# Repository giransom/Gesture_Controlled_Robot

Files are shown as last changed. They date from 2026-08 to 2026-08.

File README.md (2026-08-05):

# Gesture_Controlled_Robot
The goal of the project is for a robot car to mover based on the movement of the hand controller. This project utilizes UART communication through HC 05 bluetooth modules to create send and receive messages between an UNO &amp; Nano.

Headstone Image

# Code
Base Project Code
- [Complete Hand Module Code: Nano](Gesture_Controlled_Robot_Hand_Code.ino)
- [Complete Robot Car Module Code](Gesture_Controlled_Robot_Robot_Code.ino)
- [Bluetooth Connection Test: UNO](Bluetooth_Tester_UNO.ino)
- [Bluetooth Connection Test: BLE 33 Sense](Bluetooth_Tester_BLE_33_Sense.ino)
- [AT Mode Code: UNO](AT_Mode_UNO.ino)
- [AT Mode Code: BLE 33 Sense](AT_Mode_BLE_33_Sense.ino)

HPV Camera & Screen
- [Stream Live Video from Camera](server.py)
- [Stream Capture Images from Camera](image_stream_server.py)
- [Setting Up IP Adrdess](setup_server.py)
- [Final Camera Live Stream Code](ESP32_Camera.ino)
- [Final Display Live Stream Code](Display_Camera.ino)

# Schematics
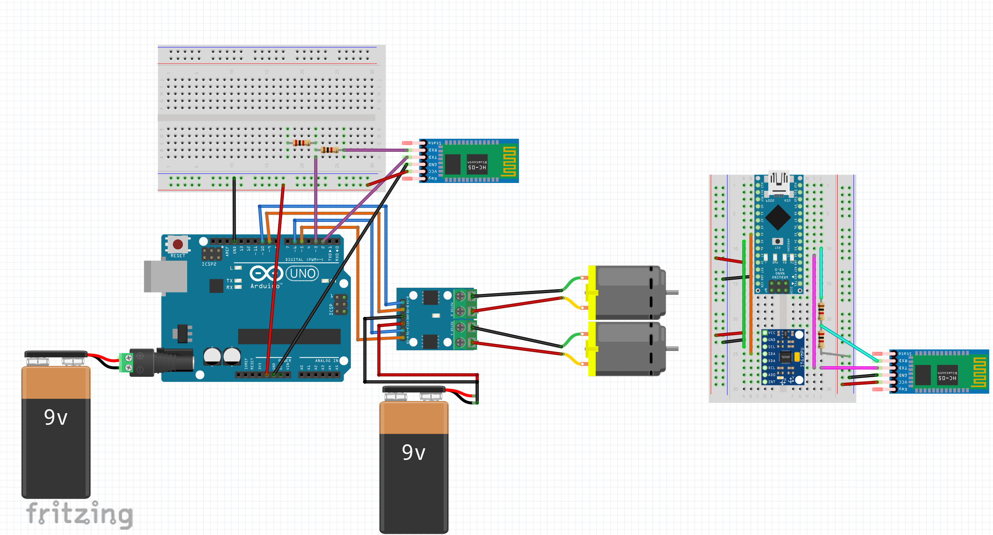
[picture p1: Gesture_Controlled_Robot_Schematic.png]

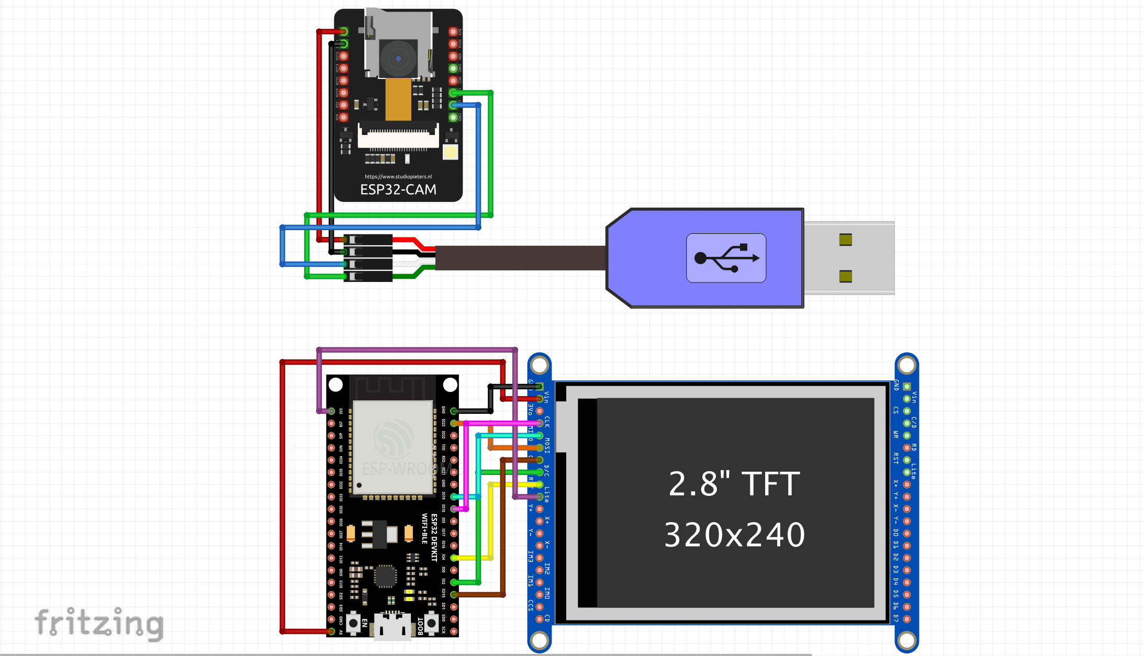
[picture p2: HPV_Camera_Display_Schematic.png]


# Project Notes: Challenges & Fixes
  In the completion of this project there were many challenges to overcome. The first challenge faced was in connecting the bluetooth modules together. I based my original wiring based on the original project I found my HC 05 modules would not enter AT mode and respond to commands. When I further researched the modules independently I found the EN pin needed to be fed 3.3 V when entering AT mode. My next challenge faced was ensuring the actual modules not only were connected by checking the blinking rate, but sending actual characters between each other. My solution found was making sure the correct baud rate was set (38400 baud) in AT mode and then setting the Arduino's Serial bauds to be different values (Uno @ 115200 and Nano BLE 33 @ 9600). My next challenge faced was providing enough voltage to the motor driver to run while disconnected from the computer. The solution to this issue was to wire a separate 9V battery to the motor driver so it had a consistent source of voltage. 
  After finishing the base model of the project I decided to add an additional HPV camera with touch screen display. In adding my addition components I ran into many issues, starting with issues of my camera connecting to the wifi. Originally when I setup my camera the streaming worked, but after restarting the camera it suddenly did not connect to wifi anymore. Eventually I found that I forgot to add an additional antenna the camera came with which prevented the board from reaching the wifi. After that initial issue it was simple to start to set up the display screen and ensure it could pick up the streamed IP website. When my display screen finally started to stream the video feed there was issues with setting ip the actual pixel setting since the JPEG decoder was not adjusted correctly.

# Bill of Materials
Base Project Parts
| **Part** | **Note** | **Price** | **Link** |
|:--:|:--:|:--:|:--:|
| Sunfounder Kit | Has main components including Arduino Uno, ultrasonic sensor, etc. | $62.99 | <a href="https://www.amazon.com/SunFounder-Compatible-Tutorials-Including-Controller/dp/B0B778L1DZ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"> Link </a> |
| Arduino Nano BLE 33 Sense | Has main components including Arduino Uno, ultrasonic sensor, etc. | $39.7 | <a href="https://www.amazon.com/Arduino-Nano-Sense-headers-ABX00070/dp/B0BQHZ88WD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"> Link </a> |
| Accelerometer | Has main components including Arduino Uno, ultrasonic sensor, etc. | $9 | <a href="https://www.amazon.com/dp/B0D2TJVMNY?ref=fed_asin_title"> Link </a> |
| HC 05 Bluetooth Modules | Has main components including Arduino Uno, ultrasonic sensor, etc. | $9 | <a href="https://www.amazon.com/DSD-TECH-HC-05-Pass-through-Communication/dp/B01G9KSAF6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"> Link </a> |
| Breadboard Kit | Has main components including Arduino Uno, ultrasonic sensor, etc. | $8.69 | <a href="https://www.amazon.com/Breadboards-Solderless-Breadboard-Distribution-Connecting/dp/B07DL13RZH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"> Link </a> |
| 9V Batteries | Has main components including Arduino Uno, ultrasonic sensor, etc. | $8.69 | <a href="https://www.amazon.com/Amazon-Basics-Performance-All-Purpose-Batteries/dp/B00MH4QM1S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"> Link </a> |
| Velcro Tape | Has main components including Arduino Uno, ultrasonic sensor, etc. | $8 | <a href="https://www.amazon.com/Art3d-Sticky-Double-Sided-Command-Adhesive/dp/B0B58FGF8H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"> Link </a> |
| DMM | Has main components including Arduino Uno, ultrasonic sensor, etc. | $9.99 | <a href="https://www.amazon.com/dp/B0CXM242J1?ref=fed_asin_title&th=1"> Link </a> |

HPV Camera & Display Attachment
| **Part** | **Note** | **Price** | **Link** |
|:--:|:--:|:--:|:--:|
| Arduino ESP 32 Camera | Has main components including Arduino Uno, ultrasonic sensor, etc. | $25.99 | <a href="https://www.amazon.com/ESP32-CAM-Development-ESP32-CAM-Bluetooth/dp/B0FLPMGHLR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"> Link </a> |
| ELGOO Arduino ESP 32 Dev Module | Has main components including Arduino Uno, ultrasonic sensor, etc. | $19.99 | <a href="https://www.amazon.com/ELEGOO-ESP-WROOM-32-Development-Bluetooth-Microcontroller/dp/B0D8T53CQ5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"> Link </a> |
| SPI TFT Display Touch Panel | Has main components including Arduino Uno, ultrasonic sensor, etc. | $11.99 | <a href="https://www.amazon.com/DIANN-ILI9341-Display-320x240-Screen/dp/B0BNQBKFCT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"> Link </a> |

# Sources
- [Original Project](https://www.hackster.io/embeddedlab786/hand-gesture-control-robot-via-bluetooth-94b13d)
- [HC 05 Bluetooth Module: Video](https://www.youtube.com/watch?v=BXXAcFOTnBo)
- [HC 05 Bluetooth Module: Manual](https://docs.google.com/document/d/1EpnEPulXQwPDSK-nKLohqPjpeXNteP2G/edit)
- [General HPV & Display Setup Instruction](https://docs.google.com/document/d/1EpnEPulXQwPDSK-nKLohqPjpeXNteP2G/edit)
- [Visual Studio Code Download](https://code.visualstudio.com/)
- [Python Download](https://www.python.org/downloads/)

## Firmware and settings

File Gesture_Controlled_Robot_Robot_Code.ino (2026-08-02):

#include <SoftwareSerial.h>
SoftwareSerial BT_Serial(2, 3); // RX, TX

#define in1 5 //Motor1 L298 Pin in1
#define in2 6 //Motor1 L298 Pin in1
#define in3 9 //Motor2 L298 Pin in1
#define in4 10 //Motoe2 L298 Pin in1

char bt_data; //variable to receive data from the serial port
int Speed = 150; //Write the Duty Cycle 0 to 255 Enable Pins for Motor Speed

void setup() {
  // put your setup code here, to run once:

Serial.begin(115200); //start serial communicartiosn at 9600bps
BT_Serial.begin(38400);

pinMode(in1, OUTPUT); //declare as output for L298 Pin in1
pinMode(in2, OUTPUT); //declare as output for L298 Pin in2
pinMode(in3, OUTPUT); //declare as output for L298 Pin in3
pinMode(in4, OUTPUT); //declare as output for L298 Pin in4

delay(200);
}

void loop() {
  // put your main code here, to run repeatedly:
if(BT_Serial.available() > 0){
  //if some data is sent, reads it and saves in state
  bt_data = BT_Serial.read();
  Serial.println(BT_Serial.read());
}

if(bt_data == 'f'){ //makes DC motors move forwards
  forward(); Speed=180;}
else if(bt_data == 'b'){ //makes motors move backwards
  backward(); Speed=180;}
else if(bt_data == 'l'){ //makes motors move turn left
  turnLeft(); Speed=250;}
else if(bt_data == 'r'){ //makes motors turn right
  turnRight(); Speed=250;}
else if(bt_data == 's'){ //makes motors stop
  stop();}


delay(50);
}

void forward(){
  digitalWrite(in1, LOW); //Right Motor forward Pin
  digitalWrite(in2, HIGH); //Right Motor backward Pin
  digitalWrite(in3, HIGH); //Left Motor backward Pin
  digitalWrite(in4, LOW); //Left Motor forward Pin
}

void backward(){
  digitalWrite(in1, HIGH); //Right Motor forward Pin
  digitalWrite(in2, LOW); //Right Motor backward Pin
  digitalWrite(in3, LOW); //Left Motor backward Pin
  digitalWrite(in4, HIGH); //Left Motor forward Pin
}

void turnRight(){
  digitalWrite(in1, HIGH); //Right Motor forward Pin
  digitalWrite(in2, LOW); //Right Motor backward Pin
  digitalWrite(in3, HIGH); //Left Motor backward Pin
  digitalWrite(in4, LOW); //Left Motor forward Pin
}

void turnLeft(){
  digitalWrite(in1, LOW); //Right Motor forward Pin
  digitalWrite(in2, HIGH); //Right Motor backward Pin
  digitalWrite(in3, LOW); //Left Motor backward Pin
  digitalWrite(in4, HIGH); //Left Motor forward Pin
}

void stop(){
  digitalWrite(in1, LOW); //Right Motor forward Pin
  digitalWrite(in2, LOW); //Right Motor backward Pin
  digitalWrite(in3, LOW); //Left Motor backward Pin
  digitalWrite(in4, LOW); //Left Motor forward Pin
}

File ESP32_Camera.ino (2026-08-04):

#include "esp_camera.h"
#include <WiFi.h>
#include <HTTPClient.h>


// ===========================
// WiFi Settings
// ===========================

const char* ssid = "Homedeco21";
const char* password = "8?9srj=64wtg";


// ===========================
// Flask Server
// ===========================

String serverIP = "192.168.68.119";

String uploadURL =
"http://" + serverIP + ":8080/upload";


// ===========================
// AI Thinker ESP32-CAM Pins
// ===========================

#define PWDN_GPIO_NUM     32
#define RESET_GPIO_NUM    -1

#define XCLK_GPIO_NUM      0
#define SIOD_GPIO_NUM     26
#define SIOC_GPIO_NUM     27

#define Y9_GPIO_NUM       35
#define Y8_GPIO_NUM       34
#define Y7_GPIO_NUM       39
#define Y6_GPIO_NUM       36
#define Y5_GPIO_NUM       21
#define Y4_GPIO_NUM       19
#define Y3_GPIO_NUM       18
#define Y2_GPIO_NUM        5

#define VSYNC_GPIO_NUM    25
#define HREF_GPIO_NUM     23
#define PCLK_GPIO_NUM     22



// ===========================
// Camera Setup
// ===========================

void startCamera()
{

  camera_config_t config;

  config.ledc_channel = LEDC_CHANNEL_0;
  config.ledc_timer = LEDC_TIMER_0;


  config.pin_d0 = Y2_GPIO_NUM;
  config.pin_d1 = Y3_GPIO_NUM;
  config.pin_d2 = Y4_GPIO_NUM;
  config.pin_d3 = Y5_GPIO_NUM;
  config.pin_d4 = Y6_GPIO_NUM;
  config.pin_d5 = Y7_GPIO_NUM;
  config.pin_d6 = Y8_GPIO_NUM;
  config.pin_d7 = Y9_GPIO_NUM;


  config.pin_xclk = XCLK_GPIO_NUM;
  config.pin_pclk = PCLK_GPIO_NUM;

  config.pin_vsync = VSYNC_GPIO_NUM;
  config.pin_href = HREF_GPIO_NUM;


  config.pin_sscb_sda = SIOD_GPIO_NUM;
  config.pin_sscb_scl = SIOC_GPIO_NUM;


  config.pin_pwdn = PWDN_GPIO_NUM;
  config.pin_reset = RESET_GPIO_NUM;


  config.xclk_freq_hz = 20000000;

  config.pixel_format = PIXFORMAT_JPEG;


config.frame_size = FRAMESIZE_QVGA;
config.jpeg_quality = 8;
  config.fb_count = 2;


  esp_err_t result = esp_camera_init(&config);
sensor_t *s = esp_camera_sensor_get();

s->set_brightness(s, 0);
s->set_contrast(s, 0);
s->set_saturation(s, -1);

  if(result != ESP_OK)
  {
    Serial.println("Camera init failed");
    while(true);
  }


  Serial.println("Camera Ready");

}



// ===========================
// WiFi
// ===========================

void connectWiFi()
{

  WiFi.mode(WIFI_STA);

  WiFi.begin(ssid,password);


  Serial.print("Connecting WiFi");


  while(WiFi.status() != WL_CONNECTED)
  {
    delay(500);
    Serial.print(".");
  }


  Serial.println();

  Serial.println("WiFi Connected");

  Serial.print("Camera IP: ");
  Serial.println(WiFi.localIP());

}



// ===========================
// Send Image
// ===========================

void sendImage()
{

  if(WiFi.status() != WL_CONNECTED)
  {
    Serial.println("WiFi disconnected");
    return;
  }


  camera_fb_t *fb = esp_camera_fb_get();


  if(!fb)
  {
    Serial.println("Camera capture failed");
    return;
  }


  HTTPClient http;


  http.begin(uploadURL);

  http.addHeader(
    "Content-Type",
    "image/jpeg"
  );


  int response =
  http.POST(
    fb->buf,
    fb->len
  );


  Serial.print("Upload response: ");
  Serial.println(response);


  http.end();


  esp_camera_fb_return(fb);

}



// ===========================
// Setup
// ===========================

void setup()
{

  Serial.begin(115200);

  delay(1000);


  connectWiFi();

  startCamera();

}



// ===========================
// Loop
// ===========================

void loop()
{

  sendImage();

  delay(100);

}

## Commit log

2026-08-02 Add Bill of Materials section to README
    Added a Bill of Materials section with details on the Sunfounder Kit.
2026-08-04 Update README with project code and camera details
    Added new project code sections and updated camera live stream code reference.
2026-08-04 Update Bill of Materials with new components
    Added new parts to the Bill of Materials section, including components for the HPV Camera & Display Attachment.
2026-08-05 Add schematics section to README
    Added schematics section with an image to the README.
2026-08-05 Update README with product listings and sources
    Added product listings and sources for Arduino components.
2026-08-05 Enhance README with project challenges and solutions
    Expanded project notes to detail challenges faced and solutions implemented during development, including Bluetooth module connection issues, motor driver voltage supply, and camera setup problems.
